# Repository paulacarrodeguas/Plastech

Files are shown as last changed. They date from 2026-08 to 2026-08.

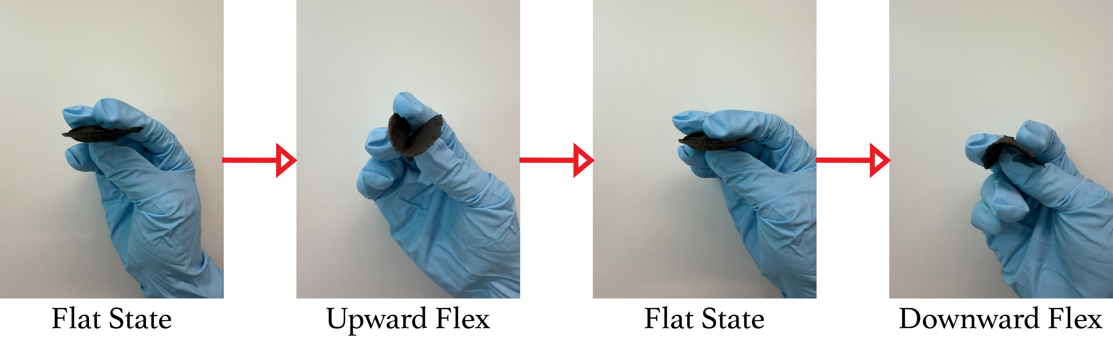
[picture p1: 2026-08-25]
Documentation/Flexible Material.jpg

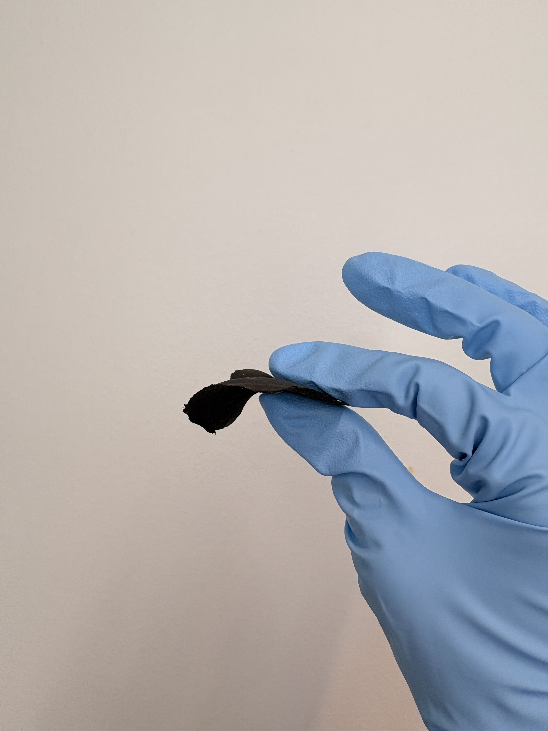
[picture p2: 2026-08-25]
Documentation/IMG_2744 (1).JPG

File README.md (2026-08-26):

# Plastech

Plastech is a 100% biodegradable, cellulose-based splint meant to replace
plaster and fiberglass casts. It has two layers: a flexible film that wraps
the limb and a filler that hardens inside it. 

My main work focused on the materials (preparing methylcellulose
formulations with different additives and characterizing them with rheology).
One part of the project was also a sensing system for the skin–splint
interface.

## Why sensors

Once a limb is in a cast, what happens against the skin is no longer
visible, so problems build up without warning. The sensing system measures
the parameters behind the most common complications:

- **Pressure** over bony prominences, where sustained pressure leads to
  pressure sores. Interface pressure also correlates with intracompartmental
  pressure, so it is relevant to compartment syndrome (Uslu & Apan, 2000).
- **Temperature gradient** between a proximal and a distal point, proposed
  as an early non-invasive sign of compartment syndrome (Tepordei et al.,
  2024).
- **Humidity** at the skin, since a damp interface causes maceration.

The FlexiForce A201-1 has been used for cast pressure monitoring before
(Tuan et al., 2019), which supports its use here.

## Sensor placement

Four pressure sensors, balancing the main bony prominences (pressure sores)
with the compartments that matter for compartment syndrome:

- **P1 — radial styloid** (bony prominence)
- **P2 — ulnar styloid** (bony prominence)
- **P3 — volar / flexor compartment** (compartment syndrome)
- **P4 — dorsal / extensor compartment** (compartment syndrome)

The two temperature sensors are placed as far apart as the forearm splint
allows, one near the elbow and one near the wrist, to capture the
proximal–distal gradient. Tepordei et al. measured this across the whole
limb; here the same principle is applied at forearm scale, with the sensors
as far apart as possible. The humidity sensor sits at the skin.

## Calibration

Each pressure sensor was calibrated individually against known weights
(0–300 g), six readings per weight, 10 s at 10 Hz. Each FSR has its own
slope and intercept. So pressure in grams comes from a per-sensor linear 
fit (R² = 0.98–0.997). The script and the equations are in `calibration/`.

## Code

`firmware/` contains two sketches:

- **plastech_sensor_node** — The ESP32 creates its own WiFi
  network and serves a small dashboard. A mobile app would be better suited for a final
  product, but a web page was enough to show that the sensors read correctly.
- **plastech_basic_readout** — prints the readings to the
  Serial Monitor (115200 baud). No WiFi, useful to check everything works, could be used in a future to send the values so an app processes them.

To use the dashboard: connect to the **PLASTECH** network (password is in
the code) and open `http://192.168.4.1/`. `/data` returns the raw line and
`/status` shows which sensors started.

## Hardware

- 4× FlexiForce A201-1 (pressure)
- MCP6004 op-amp (amplifies and linearizes the signal)
- ADS1115 16-bit ADC
- ESP32-S3 Feather
- 2× TMP117 (temperature, ±0.1 °C)
- SHT45 (humidity, ±1.0% RH)
- Li-Ion 3.7 V battery

I²C: 0x44 SHT45, 0x48 TMP117 proximal, 0x49 TMP117 distal, 0x4A ADS1115.
Schematic is in `hardware/`.

## Folders

```
firmware/     Arduino sketches
calibration/  calibration scripts, equations, plots
hardware/     schematic, block diagram
rheology/     rheology data and plots
photos/       prototype and sample photos
```

## References

- Tuan, C.-C. et al. (2019). *Sensors* 19(10), 2417.
  https://doi.org/10.3390/s19102417
- Uslu, M. M. & Apan, A. (2000). *Arch. Orthop. Trauma Surg.*
  https://doi.org/10.1007/s004020050472
- Tepordei, R.-T. et al. (2024). *J. Pers. Med.* 14(5), 477.
  https://doi.org/10.3390/jpm14050477
- Tekscan. FlexiForce Sensors — Best Practices in Electrical Integration.
  https://www.tekscan.com/resources/datasheets-guides/best-practices-electrical-integration-flexiforce-sensor

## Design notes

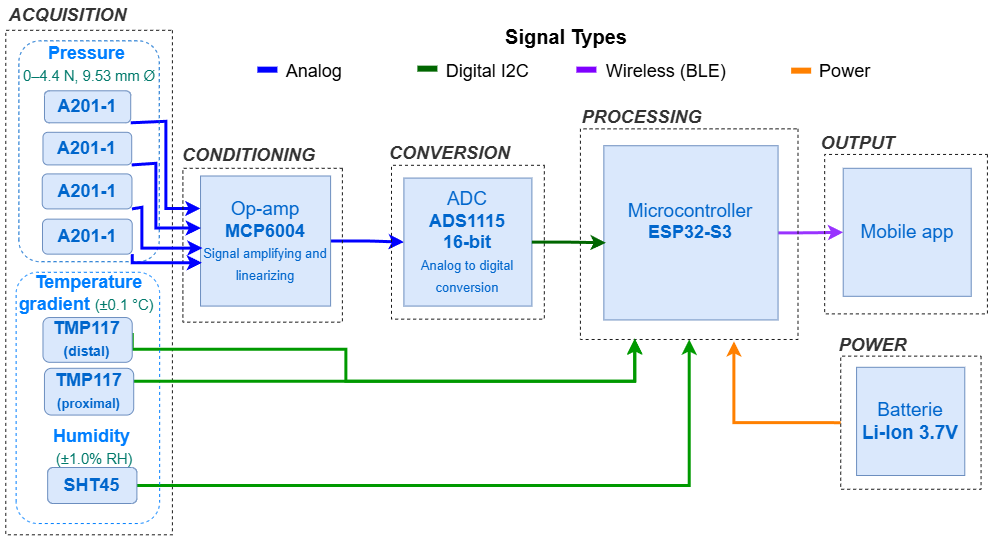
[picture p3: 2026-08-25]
Hardware/BlockDiagram.drawio.png

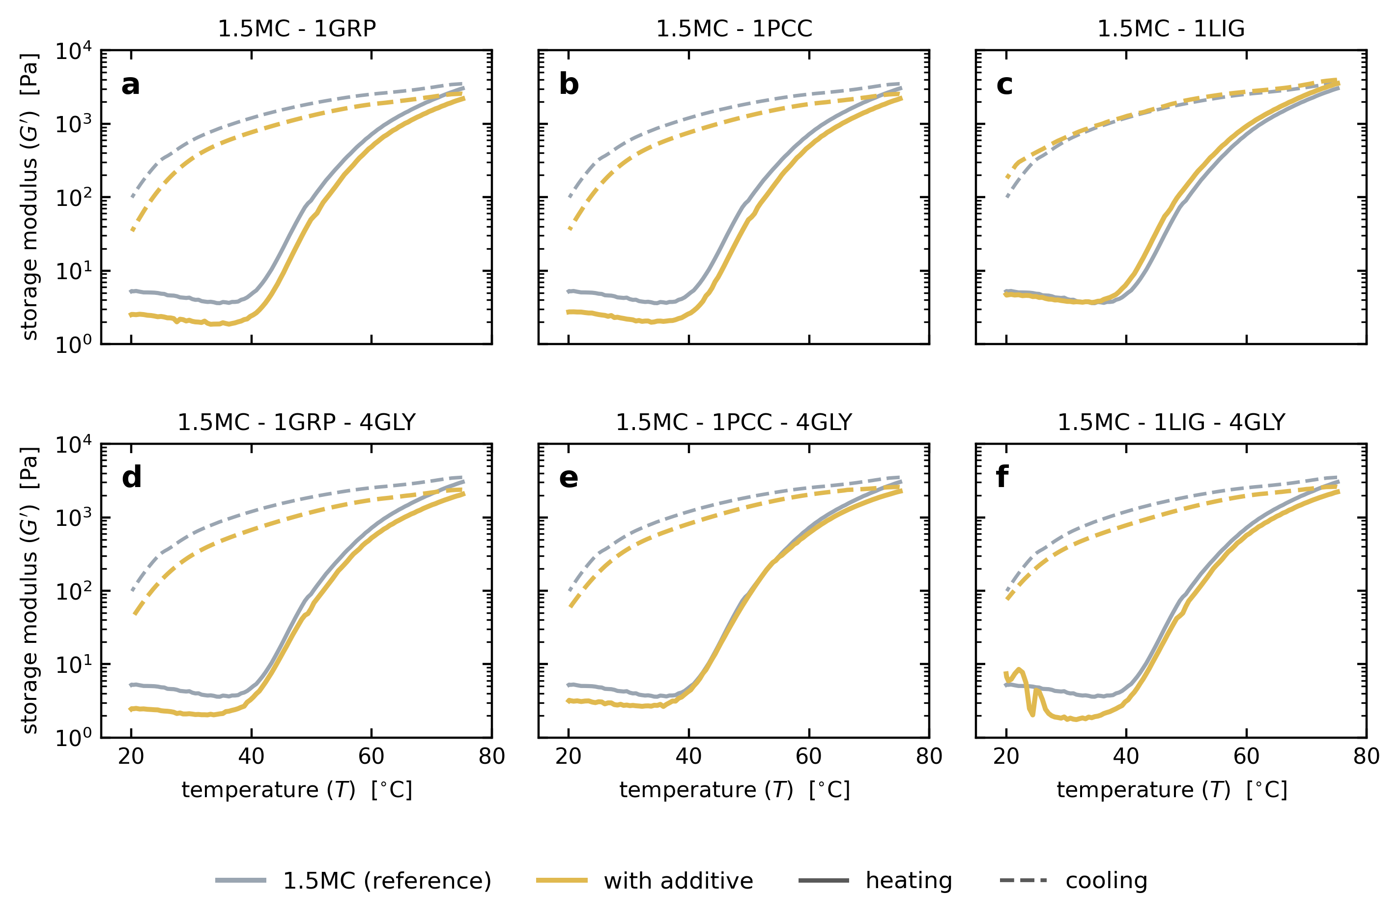
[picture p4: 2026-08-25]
Rheometry/temperature_sweeps_grid.png

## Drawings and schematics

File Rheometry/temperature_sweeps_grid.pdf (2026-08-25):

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

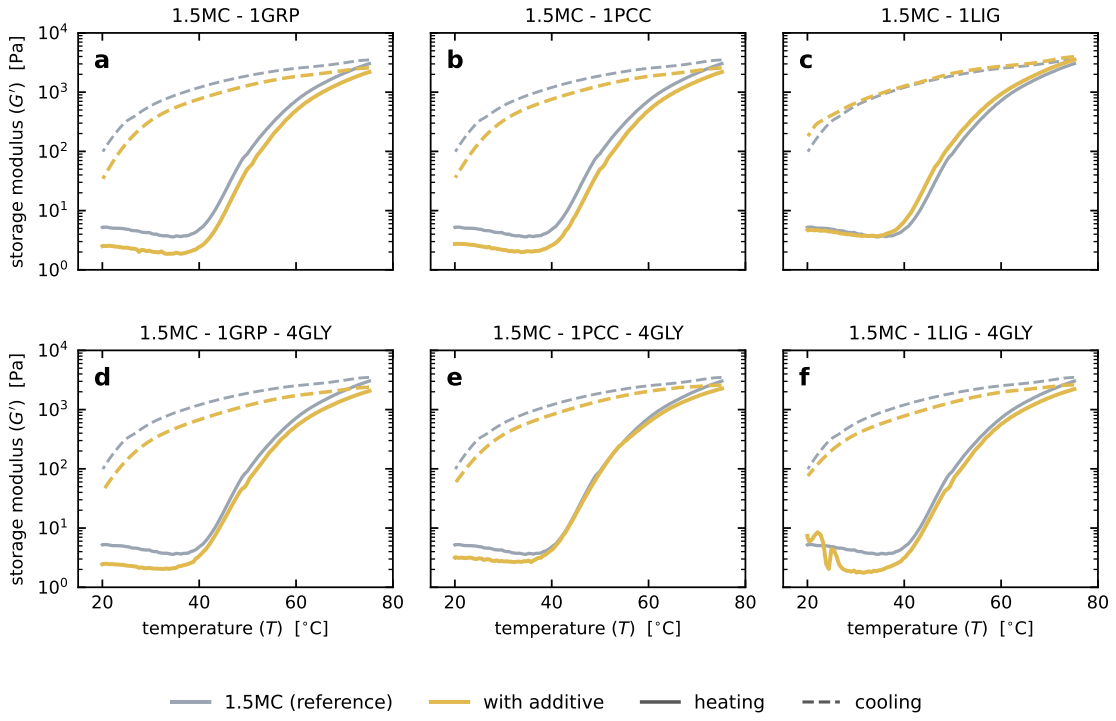
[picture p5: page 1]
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

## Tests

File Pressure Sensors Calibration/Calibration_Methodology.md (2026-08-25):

# Calibration equations — FlexiForce A201-1

Four pressure channels, each calibrated individually.

`counts` = raw ADS1115 reading (GAIN_ONE). 
`grams`  = force on the sensor.

| Channel | counts = a·g + b | grams = (counts − b) / a | R² | Valid range |
|---|---|---|---|---|
| 0 | counts = 58.4·g + 4268  | grams = (counts − 4268) / 58.4 | 0.9968 | 0–300 g |
| 1 | counts = 50.8·g + 4275  | grams = (counts − 4275) / 50.8 | 0.9957 | 0–300 g |
| 2 | counts = 49.8·g + 4645  | grams = (counts − 4645) / 49.8 | 0.9834 | 0–300 g |
| 3 | counts = 54.6·g + 4263  | grams = (counts − 4571) / 34.2 | 0.9967 | 0–300 g |

## Conditions

- Rigid puck over the ~9.53 mm sensing area
- Weights: 0, 5, 10, 20, 50, 100, 200, 300 g (made on the lab balance)
- 6 repetitions per weight, averaged; fixed settling time per weight to keep
  drift consistent across points

## Protocol / method references

- Weight set and 6×10 s averaging protocol: Kao et al., Sensors 2021,
  21(17):5681, doi:10.3390/s21175681
- FSR conditioning before calibration: Tekscan FlexiForce Best Practices;
  Hall, Desmoulin & Milner, J Biomech 2008, doi:10.1016/j.jbiomech.2008.09.031
- Per-sensor calibration requirement and part-to-part variation: Tekscan
  FlexiForce Best Practices

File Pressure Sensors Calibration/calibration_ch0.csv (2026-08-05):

grams | counts | std
0.0 | 4594.5 | 0.0
5.0 | 4722.7 | 14.7
10.0 | 4932.9 | 3.8
20.0 | 5708.3 | 12.0
50.0 | 6489.5 | 58.2
100.0 | 9856.4 | 92.1
200.0 | 15722.0 | 233.1
300.0 | 22099.1 | 247.5

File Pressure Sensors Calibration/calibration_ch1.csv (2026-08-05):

grams | counts | std
0.0 | 4599.3 | 0.1
5.0 | 4599.5 | 0.1
10.0 | 4698.8 | 49.3
20.0 | 4907.8 | 21.9
50.0 | 6321.8 | 18.3
100.0 | 9926.8 | 124.7
200.0 | 14671.7 | 192.2
300.0 | 19283.8 | 751.8

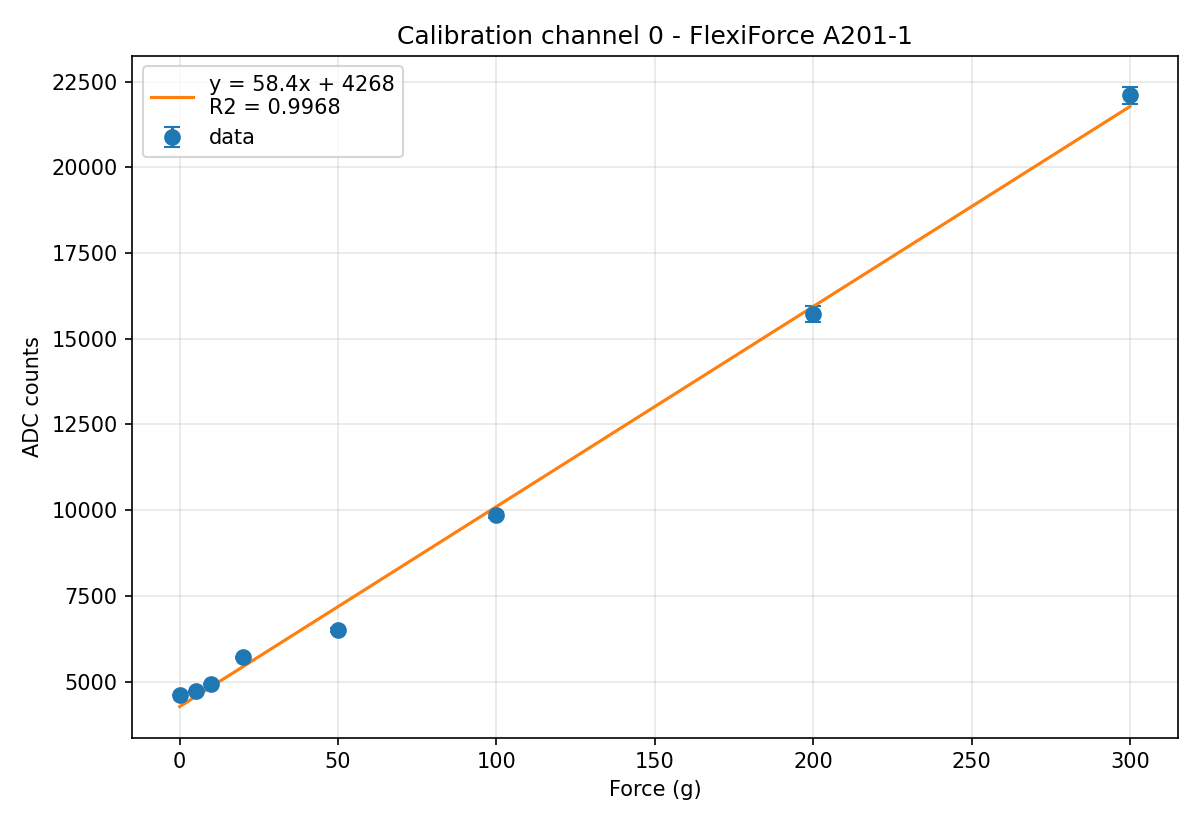
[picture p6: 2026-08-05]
Pressure Sensors Calibration/calibration_ch0.png

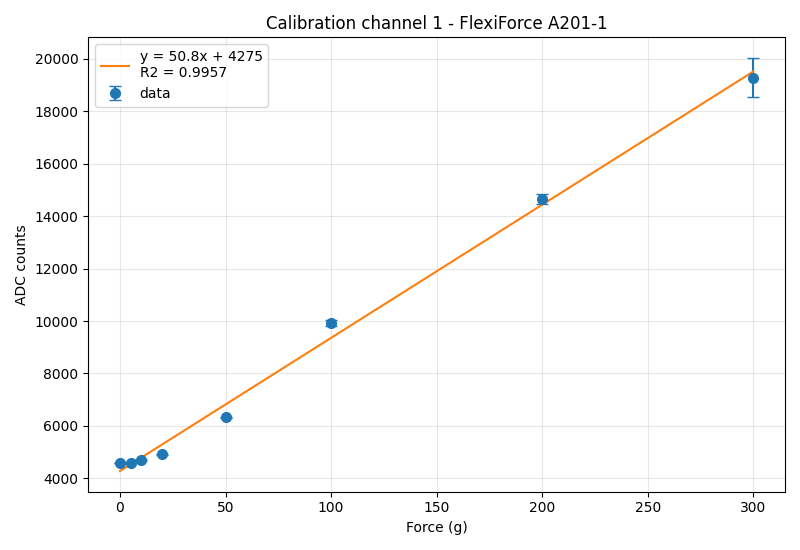
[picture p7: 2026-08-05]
Pressure Sensors Calibration/calibration_ch1.png

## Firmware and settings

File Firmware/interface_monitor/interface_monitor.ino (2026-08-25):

/*
 * PLASTECH - interface monitor
 * -----------------------------
 * Firmware for the Plastech splint sensor node.
 *
 * The ESP32 reads the sensors and serves the values over its own WiFi
 * network. Connect to the network and open the page in a browser — no
 * app required. A mobile app would be more suitable for a final product,
 * but a web page is enough to verify that the sensors read correctly.
 *
 * Sensors:
 *   - 4 pressure channels (FSR) read through the ADS1115 and converted
 *     to grams. Each sensor has its own calibration (slope + intercept)
 *     and they are not interchangeable. The goal is to alert the risk of pressure sores and compartment syndrome when the interface pressure is too high.
 *   - proximal and distal temperature (2x TMP117) and their difference to prevent compartment syndrome
 *   - temperature and humidity at the skin interface (SHT45) to avoid skin problems like maceration.
 *
 * Usage:
 *   Connect to the "PLASTECH" WiFi network (password below) and open:
 *     http://192.168.4.1/          dashboard
 *     http://192.168.4.1/data      raw values: P1,P2,P3,P4,gradient,T_micro,RH
 *     http://192.168.4.1/status    sensor status + temperatures for debugging
 *
 * I2C addresses:
 *   0x44  humidity/temperature (SHT45)
 *   0x48  proximal temperature (TMP117)
 *   0x49  distal temperature (TMP117)
 *   0x4A  pressure ADC (ADS1115)
 */

#include <Wire.h>
#include <WiFi.h>
#include <WebServer.h>
#include <Adafruit_ADS1X15.h>
#include <Adafruit_TMP117.h>
#include <Adafruit_SHT4x.h>

const char* AP_SSID = "PLASTECH";
const char* AP_PASS = "plastech2026";

WebServer server(80);

Adafruit_ADS1115 ads;
Adafruit_TMP117 tmp_prox;
Adafruit_TMP117 tmp_dist;
Adafruit_SHT4x sht;

bool ads_ok = false, prox_ok = false, dist_ok = false, sht_ok = false;
float last_prox = -1, last_dist = -1;

float slope[4]     = {58.4, 50.8, 49.8, 54.6};
float intercept[4] = {4268, 4275, 4645, 4263};

float toGrams(int16_t counts, int ch) {
  float g = (counts - intercept[ch]) / slope[ch];
  if (g < 0) g = 0;
  return g;
}

// P1,P2,P3,P4,gradient,T_micro,RH
String buildLine() {
  float p[4] = {0, 0, 0, 0};
  if (ads_ok) for (int i = 0; i < 4; i++) p[i] = toGrams(ads.readADC_SingleEnded(i), i);

  float gradient = 0;
  if (prox_ok) { sensors_event_t e; tmp_prox.getEvent(&e); last_prox = e.temperature; }
  if (dist_ok) { sensors_event_t e; tmp_dist.getEvent(&e); last_dist = e.temperature; }
  if (prox_ok && dist_ok) gradient = last_prox - last_dist;

  float t_micro = -1, rh = -1;
  if (sht_ok) {
    sensors_event_t hum, temp;
    sht.getEvent(&hum, &temp);
    t_micro = temp.temperature;
    rh = hum.relative_humidity;
  }

  String s = "";
  s += String(p[0],1) + "," + String(p[1],1) + "," + String(p[2],1) + "," + String(p[3],1) + ",";
  s += String(gradient,2) + ",";
  s += String(t_micro,2) + "," + String(rh,1);
  return s;
}

// ------------------------------------------------------------------
// dashboard
// ------------------------------------------------------------------
const char PAGE[] PROGMEM = R"HTML(<!DOCTYPE html>
<html lang="en">
<head>
<meta charset="utf-8">
<meta name="viewport" content="width=device-width,initial-scale=1">
<title>Plastech</title>
<style>
:root{
  --bg:#0B1416; --panel:#122024; --edge:#1E3238;
  --ink:#E4EFEC; --dim:#7E9A9B;
  --ok:#8FD6BA; --watch:#E8B65A; --alert:#E8685A;
  --mono:ui-monospace,SFMono-Regular,Menlo,Consolas,monospace;
  --sans:system-ui,-apple-system,"Segoe UI",Roboto,sans-serif;
}
*{box-sizing:border-box}
body{margin:0;background:var(--bg);color:var(--ink);font-family:var(--sans);
     -webkit-text-size-adjust:100%}
.bar{display:flex;align-items:center;gap:10px;padding:14px 18px;
     border-bottom:1px solid var(--edge);font-size:12px;letter-spacing:.14em;
     text-transform:uppercase;color:var(--dim)}
.bar b{color:var(--ink);font-weight:600;letter-spacing:.14em}
.live{margin-left:auto;display:flex;align-items:center;gap:7px;letter-spacing:.08em}
#pulse{width:7px;height:7px;border-radius:50%;background:var(--ok)}
.stale #pulse{background:var(--alert)}
.wrap{display:grid;gap:18px;padding:18px;max-width:900px;margin:0 auto}
@media(min-width:760px){.wrap{grid-template-columns:300px 1fr;align-items:start}}

.limb{background:var(--panel);border:1px solid var(--edge);border-radius:14px;padding:8px}
.limb svg{width:100%;height:auto;display:block}
.pt{transition:r .25s ease,fill .25s ease}
@media(prefers-reduced-motion:reduce){.pt{transition:none}}
.ptlabel{font-family:var(--mono);font-size:11px;fill:var(--ink)}
.ptname{font-family:var(--mono);font-size:8px;fill:var(--dim)}

.rows{display:grid;gap:12px}
.row{background:var(--panel);border:1px solid var(--edge);border-radius:14px;
     padding:16px 18px;display:flex;align-items:baseline;gap:14px}
.row .k{font-size:11px;letter-spacing:.12em;text-transform:uppercase;color:var(--dim)}
.row .v{margin-left:auto;font-family:var(--mono);font-size:34px;
        font-variant-numeric:tabular-nums;line-height:1}
.row .u{font-family:var(--mono);font-size:13px;color:var(--dim)}
.row.big .v{font-size:46px}
.ok .v{color:var(--ok)} .watch .v{color:var(--watch)} .alert .v{color:var(--alert)}
</style>
</head>
<body>

<div class="bar" id="bar">
  <b>Plastech</b>
  <span class="live"><span id="pulse"></span><span id="age">--</span></span>
</div>

<div class="wrap">

  <div class="limb">
    <svg viewBox="0 0 200 400">
      <path d="M78 24 C68 120 60 260 58 372 L142 372 C140 260 132 120 122 24 Z"
            fill="#16282D" stroke="#24424A" stroke-width="1.5"/>

      <circle class="pt" id="c0" cx="82"  cy="112" r="8" fill="#8FD6BA" opacity=".85"/>
      <circle class="pt" id="c1" cx="120" cy="112" r="8" fill="#8FD6BA" opacity=".85"/>
      <circle class="pt" id="c2" cx="76"  cy="264" r="8" fill="#8FD6BA" opacity=".85"/>
      <circle class="pt" id="c3" cx="126" cy="264" r="8" fill="#8FD6BA" opacity=".85"/>

      <text class="ptname" x="40"  y="98">P1</text>
      <text class="ptname" x="150" y="98">P2</text>
      <text class="ptname" x="34"  y="250">P3</text>
      <text class="ptname" x="156" y="250">P4</text>
      <text class="ptlabel" id="t0" x="40"  y="118" text-anchor="end">--</text>
      <text class="ptlabel" id="t1" x="160" y="118">--</text>
      <text class="ptlabel" id="t2" x="34"  y="270" text-anchor="end">--</text>
      <text class="ptlabel" id="t3" x="166" y="270">--</text>
    </svg>
  </div>

  <div class="rows">
    <div class="row big ok" id="r_grad">
      <span class="k">Temperature gradient</span>
      <span class="v" id="v_grad">--</span><span class="u">&deg;C</span>
    </div>
    <div class="row ok" id="r_temp">
      <span class="k">Temperature</span>
      <span class="v" id="v_temp">--</span><span class="u">&deg;C</span>
    </div>
    <div class="row ok" id="r_rh">
      <span class="k">Humidity</span>
      <span class="v" id="v_rh">--</span><span class="u">%</span>
    </div>
  </div>

</div>

<script>
const TH = {
  p:    {watch:150, alert:250},
  grad: {watch:1.0, alert:2.0},
  rh:   {watch:70,  alert:80}
};
const P_FULL = 300;

const COL = {ok:'#8FD6BA', watch:'#E8B65A', alert:'#E8685A'};
const level = (x,t) => x >= t.alert ? 'alert' : x >= t.watch ? 'watch' : 'ok';
const setRow = (el,lv) => { el.className = 'row ' + (el.id==='r_grad'?'big ':'') + lv; };

let lastOk = 0;

async function tick(){
  try{
    const r = await fetch('/data',{cache:'no-store'});
    const v = (await r.text()).trim().split(',').map(Number);
    if(v.length !== 7 || v.some(n => Number.isNaN(n))) throw new Error('bad line');

    for(let i=0;i<4;i++){
      const g = v[i], lv = level(g, TH.p);
      const c = document.getElementById('c'+i);
      c.setAttribute('r', 8 + 16*Math.min(1, g/P_FULL));
      c.setAttribute('fill', COL[lv]);
      document.getElementById('t'+i).textContent = g.toFixed(0);
    }

    const grad = v[4];
    v_grad.textContent = (grad>0?'+':'') + grad.toFixed(2);
    setRow(r_grad, level(Math.abs(grad), TH.grad));

    v_temp.textContent = v[5].toFixed(1);
    v_rh.textContent   = v[6].toFixed(0);
    setRow(r_rh, level(v[6], TH.rh));

    lastOk = Date.now();
    bar.classList.remove('stale');
  }catch(e){
    if(Date.now() - lastOk > 3000) bar.classList.add('stale');
  }
  age.textContent = lastOk ? Math.round((Date.now()-lastOk)/1000)+'s' : 'no signal';
}
tick();
setInterval(tick, 500);
</script>
</body>
</html>)HTML";

void handleRoot() {
  server.sendHeader("Cache-Control", "no-store");
  server.send(200, "text/html", String(FPSTR(PAGE)));
}

void handleData() {
  server.sendHeader("Cache-Control", "no-store");
  server.send(200, "text/plain", buildLine());
}

void handleStatus() {
  String live = buildLine();
  String s = "Plastech sensor node\n\n";
  s += "ADC:           "; s += ads_ok  ? "OK" : "NOT FOUND"; s += "\n";
  s += "Temp proximal: "; s += prox_ok ? "OK" : "NOT FOUND"; s += "\n";
  s += "Temp distal:   "; s += dist_ok ? "OK" : "NOT FOUND"; s += "\n";
  s += "Microclimate:  "; s += sht_ok  ? "OK" : "NOT FOUND"; s += "\n\n";
  s += "Order: P1,P2,P3,P4,gradient,T_micro,RH\n";
  s += "Live:  " + live + "\n\n";
  s += "Temps (debug): " + String(last_prox,2) + " / " + String(last_dist,2) + "\n";
  s += "-1 means that sensor did not start.\n";
  server.send(200, "text/plain", s);
}

void scanI2C() {
  Serial.println("--- I2C scan ---");
  int found = 0;
  for (uint8_t addr = 1; addr < 127; addr++) {
    Wire.beginTransmission(addr);
    if (Wire.endTransmission() == 0) {
      Serial.print("  device at 0x"); Serial.println(addr, HEX);
      found++;
    }
  }
  if (found == 0) Serial.println("  nothing found - check wiring");
  Serial.println("----------------");
}

void setup() {
  Serial.begin(115200);
  delay(1500);

  WiFi.softAP(AP_SSID, AP_PASS);
  Serial.println();
  Serial.print("Hotspot up: "); Serial.println(AP_SSID);
  Serial.print("Open http://"); Serial.print(WiFi.softAPIP()); Serial.println("/");

  server.on("/", handleRoot);
  server.on("/data", handleData);
  server.on("/status", handleStatus);
  server.begin();
  Serial.println("Server started");

  Wire.begin();
  Wire.setTimeOut(50);
  scanI2C();

  ads_ok = ads.begin(0x4A);
  if (ads_ok) ads.setGain(GAIN_ONE);
  Serial.print("ADC: ");            Serial.println(ads_ok  ? "OK" : "FAIL");

  prox_ok = tmp_prox.begin(0x48);
  Serial.print("Temp proximal: ");  Serial.println(prox_ok ? "OK" : "FAIL");

  dist_ok = tmp_dist.begin(0x49);
  Serial.print("Temp distal: ");    Serial.println(dist_ok ? "OK" : "FAIL");

  sht_ok = sht.begin();
  Serial.print("Microclimate: ");   Serial.println(sht_ok  ? "OK" : "FAIL");

  Serial.println("Setup complete");
}

void loop() {
  server.handleClient();
}

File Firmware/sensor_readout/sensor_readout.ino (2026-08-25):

/*
 * PLASTECH - basic sensor readout
 *
 * Reads all the sensors on the Plastech splint node and prints the values
 * to the Serial Monitor. Pressure is converted to grams using a per-sensor
 * calibration (each FSR has its own slope and intercept, they are not
 * interchangeable). 
 * Open the Serial Monitor at 115200 baud to see the values.
 *
 * I2C addresses:
 *   0x44  humidity/temperature (SHT45)
 *   0x48  proximal temperature (TMP117)
 *   0x49  distal temperature (TMP117)
 *   0x4A  pressure ADC (ADS1115)
 */

#include <Wire.h>
#include <Adafruit_ADS1X15.h>
#include <Adafruit_TMP117.h>
#include <Adafruit_SHT4x.h>

Adafruit_ADS1115 ads;
Adafruit_TMP117 tmp_prox;
Adafruit_TMP117 tmp_dist;
Adafruit_SHT4x sht;

float slope[4]     = {58.4, 50.8, 49.8, 54.6};
float intercept[4] = {4268, 4275, 4645, 4263};

float toGrams(int16_t counts, int ch) {
  float g = (counts - intercept[ch]) / slope[ch];
  if (g < 0) g = 0;
  return g;
}

void setup() {
  Serial.begin(115200);
  delay(1500);
  Wire.begin();

  ads.begin(0x4A);
  ads.setGain(GAIN_ONE);
  tmp_prox.begin(0x48);
  tmp_dist.begin(0x49);
  sht.begin();
}

void loop() {
  float p[4];
  for (int i = 0; i < 4; i++) p[i] = toGrams(ads.readADC_SingleEnded(i), i);

  sensors_event_t ep, ed;
  tmp_prox.getEvent(&ep);
  tmp_dist.getEvent(&ed);
  float gradient = ep.temperature - ed.temperature;

  sensors_event_t hum, temp;
  sht.getEvent(&hum, &temp);

  Serial.print("P1: "); Serial.print(p[0], 1); Serial.print(" g   ");
  Serial.print("P2: "); Serial.print(p[1], 1); Serial.print(" g   ");
  Serial.print("P3: "); Serial.print(p[2], 1); Serial.print(" g   ");
  Serial.print("P4: "); Serial.print(p[3], 1); Serial.print(" g   ");
  Serial.print("T_prox: "); Serial.print(ep.temperature, 2); Serial.print(" C   ");
  Serial.print("T_dist: "); Serial.print(ed.temperature, 2); Serial.print(" C   ");
  Serial.print("gradient: "); Serial.print(gradient, 2); Serial.print(" C   ");
  Serial.print("T_skin: "); Serial.print(temp.temperature, 2); Serial.print(" C   ");
  Serial.print("RH: "); Serial.print(hum.relative_humidity, 1); Serial.println(" %");

  delay(500);
}

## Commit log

2026-08-05 initial commit: calibration
    [calibration_ch0.csv, calibration_ch1.csv, calibration_ch2.csv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]
2026-08-05 initial commit: calibration script
